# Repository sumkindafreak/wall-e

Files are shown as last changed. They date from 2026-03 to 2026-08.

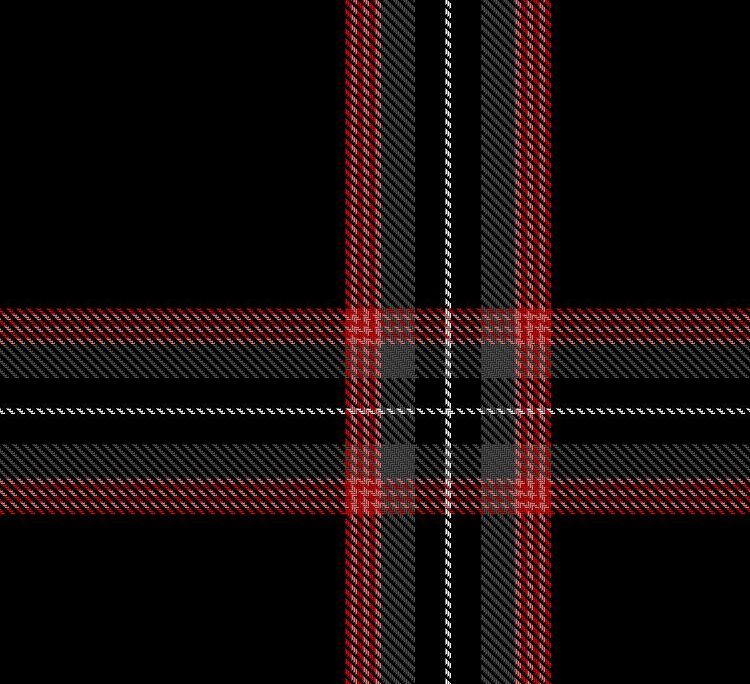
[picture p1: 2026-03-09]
wall-e electronic mounts/tartanimageprototype.jpeg

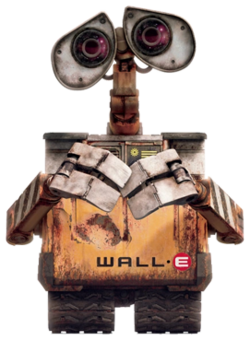
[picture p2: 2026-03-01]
webui/assets/walle-character.png

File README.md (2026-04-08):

# WALL-E Multi-Node Robotics Platform




Distributed firmware for a life-size **WALL-E**-style robot: multiple **ESP32** nodes, a **browser operator UI (LROS)**, shared libraries, and coordination over **Wi-Fi**, **ESP-NOW**, **OTA**, and a **node health** heartbeat.

**Repository:** [github.com/sumkindafreak/wall-e](https://github.com/sumkindafreak/wall-e)

---

## Table of contents

1. [Goals](#high-level-goals)
2. [Architecture](#architecture)
3. [Nodes at a glance](#nodes-at-a-glance)
4. [Communication](#communication-stack)
5. [Hardware overview](#hardware-overview)
6. [Setup](#setup)
7. [Development workflow](#development-workflow)
8. [Media](#media-placeholders)
9. [Roadmap](#roadmap)
10. [Documentation index](#documentation-index)

---

## High-level goals

| Goal | How the repo supports it |
|---|---|
| **Separation of concerns** | No single MCU runs UI, motors, audio, vision, and charging logic together. |
| **Low-latency control** | Master ↔ base uses **ESP-NOW** with packed structs; same RF channel as the base AP. |
| **Observability** | **Node health** (`WNHT`) and dock **beacon** packets expose state to the base and UI. |
| **Safe docking** | Dock station manages charge current, presence sensing, and **IR alignment** hints. |
| **Operator flexibility** | Physical **CYD master**, optional **LROS** in a browser, both ultimately commanding the **base**. |

---

## Architecture

### Diagram (Mermaid)

> Renders on GitHub; for plain text see the ASCII block below.

```mermaid
flowchart TB
  subgraph operator["Operator layer"]
    MC[wall_e_master_controller\nCYD touchscreen]
    WEB[webui / LROS\nbrowser]
  end

  subgraph brain["Base brain"]
    BASE[main_wall_E_base\nESP32-S3]
  end

  subgraph satellites["Satellite nodes"]
    AUD[audio_esp]
    VIS[vision_node / vision_node_arduino]
  end

  subgraph home["Home / charge"]
    DOCK[dock_station]
  end

  MC -->|"ESP-NOW ControlPacket / TelemetryPacket"| BASE
  WEB -->|"HTTP API"| BASE
  AUD <-->|"ESP-NOW"| BASE
  VIS -->|"ESP-NOW VisionPacket"| BASE
  BASE <-->|"ESP-NOW beacon + commands"| DOCK
  MC -.->|"same Wi-Fi channel"| BASE
  AUD -.->|"same channel"| BASE
  VIS -.->|"same channel"| BASE
  DOCK -.->|"optional home Wi-Fi"| DOCK
```

### Diagram (ASCII)

```
  ┌─────────────────────┐         ┌─────────────────────┐
  │ Master controller   │         │ Web UI (LROS)       │
  │ (ESP32 + touch)     │         │ Browser → HTTP      │
  └──────────┬──────────┘         └──────────┬──────────┘
             │ ESP-NOW                      │ HTTP
             │ Control / Telemetry           │
             ▼                               ▼
  ┌──────────────────────────────────────────────────────┐
  │ main_wall_E_base — Base brain (ESP32-S3)              │
  │ Motors · servos · AP · web server · ESP-NOW hub       │
  └─┬──────────────┬──────────────┬──────────────────────┘
    │              │              │
    │ ESP-NOW      │ ESP-NOW      │ ESP-NOW
    ▼              ▼              ▼
┌────────┐   ┌──────────┐   ┌─────────────┐
│ audio  │   │ vision   │   │ dock_station │
│ _esp   │   │ _node     │   │ charge + IR  │
└────────┘   └──────────┘   └─────────────┘
```

---

## Nodes at a glance

| Node | Folder | Responsibility |
|---|---|---|
| **Master controller** | `wall_e_master_controller/` | Touch UI, `ControlPacket` TX, `TelemetryPacket` RX; optional **SD card** (SPI) for macros, logs, profiles — see [wall_e_master_controller/README.md](wall_e_master_controller/README.md). |
| **Base (locomotion)** | `main_wall_E_base/` | Motors, servos, Wi-Fi AP, HTTP (LROS, motion policy, sequences, optional EVE UART bridge), ESP-NOW RX/TX, docking FSM, node health registry. |
| **Audio** | `audio_esp/` | Audio / DFPlayer path; ESP-NOW side channel to base. |
| **Vision** | `vision_node/` or `vision_node_arduino/` | Camera + motion; `VisionPacket_t` to base. |
| **Dock** | `dock_station/` | Charging, sensors, IR alignment receivers, dock beacon + `ir_align_hint`. |
| **Web UI** | `webui/` | Static LROS assets; talks to **base** over HTTP (not ESP-NOW). |

Per-folder details: [wall_e_master_controller/README.md](wall_e_master_controller/README.md) · [main_wall_E_base/README.md](main_wall_E_base/README.md) · [audio_esp/README.md](audio_esp/README.md) · [vision_node/README.md](vision_node/README.md) · [dock_station/README.md](dock_station/README.md) · [webui/README.md](webui/README.md) · [lib/README.md](lib/README.md)

---

## Communication stack

| Layer | Mechanism | Typical use |
|---|---|---|
| **Operator → base (real-time)** | ESP-NOW | `ControlPacket` / `TelemetryPacket` ([protocol.h](wall_e_master_controller/protocol.h)). |
| **Browser → base** | HTTP on LAN or AP | LROS fetches JSON or forms; see `web_server.cpp` on base. |
| **Vision / audio ↔ base** | ESP-NOW | Magic + length dispatch in base receiver. |
| **Base ↔ dock** | ESP-NOW | `DockBeaconPacket_t` (~10 Hz when Wi-Fi enabled on dock), dock commands. |
| **Heartbeat** | ESP-NOW | `WalleNodeHealthPacket_t` — magic `WNHT`, versioned struct ([node_health_protocol.h](main_wall_E_base/main/node_health_protocol.h)). |
| **Provisioning / OTA** | Wi-Fi STA/AP | Base AP `WALL-E-Control`; OTA [OTA_README.md](OTA_README.md). |

**Critical:** ESP-NOW peers must use the **same Wi-Fi channel** as the base access point (see [ARCHITECTURE.md](ARCHITECTURE.md)).

---

## Hardware overview

| Role | MCU (typical) | Notes |
|---|---|---|
| Master | ESP32 (e.g. CYD 2432S028) | TFT + touch; no motors. |
| Base | ESP32-S3 | Tank drive, servos (I2C PWM), VL53L1X, obstacle bumpers; no modulated **IR TX** toward the dock in firmware. |
| Audio | ESP32-S3 | DFPlayer or project-specific audio chain. |
| Vision | ESP32-S3 + PSRAM | OV2640; pin map is board-specific. |
| Dock | ESP32-S3 | Charge MOSFET, ACS712, VL6180 I2C, TSOP IR receivers, NeoPixel, TFT. |

**Dock alignment:** WALL-E emits **modulated IR** from two LEDs; the dock’s two receivers drive **`ir_align_hint`** on the beacon; the base **ALIGN** state uses that over ESP-NOW.

**Pins:** Authoritative maps live in each project’s `*_config.h`. README tables are summaries only.

---

## Setup

### Prerequisites

- [PlatformIO](https://platformio.org/) (recommended) **or** Arduino IDE 2.x + ESP32 board support.
- USB cable per module; serial **115200** baud unless a README says otherwise.

### Clone and build

```bash
git clone https://github.com/sumkindafreak/wall-e.git
cd wall-e
```

Examples:

```bash
cd main_wall_E_base && pio run -e wall_e_brain_s3
cd ../wall_e_master_controller && pio run -e cyd_esp32_2432s028
cd ../dock_station && pio run -e dock_esp32
```

Shared Arduino libraries: [`lib/`](lib/README.md) — referenced via `lib_extra_dirs` in PlatformIO.

### OTA

See **[OTA_README.md](OTA_README.md)** — web update URL for the base, `espota`, and `ota_build_all` scripts.

### RF / MAC / channel

- After flashing, each ESP32 has a factory **Wi-Fi MAC**; any stored peer list may need refresh.
- Align **Wi-Fi channel** with the base AP for ESP-NOW (document your router/AP channel if nodes use STA).
- **Dock ID:** `DOCK_ID` in `dock_config.h` — set uniquely if multiple docks exist.

---

## Development workflow

1. **Pick a node** — Build only what you change (`pio run -e <env>`).
2. **Keep protocols in sync** — `dock_protocol.h` and `node_health_protocol.h` are duplicated in several trees until consolidated; change all copies or document follow-up.
3. **Test on hardware** — Note board variant (DevKit, CYD, etc.) in PRs.
4. **Document** — Update the module `README.md` when pins, env names, or protocols change.

More detail: [CONTRIBUTING.md](CONTRIBUTING.md).

---

## Media placeholders

| Slot | Suggested path |
|---|---|
| Hero build photo | `docs/media/hero.jpg` |
| Master UI | `docs/media/controller.jpg` |
| Dock + robot | `docs/media/dock.jpg` |
| Demo GIF | `docs/media/demo.gif` |

Create `docs/media/` when you add assets, or host externally and link here.

---

## Roadmap

| Item | Notes |
|---|---|
| Single **`protocols/`** include tree | Remove duplicate headers; CI compile check. |
| Vision channel sync guide | One doc for “set router channel = base channel”. |
| LROS ↔ base WebSocket (optional) | Lower latency than polling for some panels. |
| CI matrix | Build `main_wall_E_base`, `dock_station`, `wall_e_master_controller` on push. |
| SPDX license file | Clarify redistribution terms. |

---

## Documentation index

| Document | Content |
|---|---|
| [ARCHITECTURE.md](ARCHITECTURE.md) | Design philosophy, protocols, docking, OTA, WebUI chain, motion authority (LROS vs CYD). |
| [CONTRIBUTING.md](CONTRIBUTING.md) | Branches, commits, conventions, new nodes, LROS. |
| [FOLDER_STRUCTURE.md](FOLDER_STRUCTURE.md) | Optional repo reorganization (no code moves yet). |
| [REPO_AUDIT.md](REPO_AUDIT.md) | Gaps, naming, refactors to consider. |
| [OTA_README.md](OTA_README.md) | Over-the-air updates. |

---

## License

Add a `LICENSE` file to the repository root when you choose a license (MIT, Apache-2.0, etc.). Until then, treat usage as **all rights reserved** unless you state otherwise.

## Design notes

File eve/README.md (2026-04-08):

# EVE companion firmware (ESP32-S3)

UART-framed link to WALL-E (hand pogo), state machine, and hooks for eyes / ToF / servos / NeoPixel / DFPlayer.

## Requirements

- [PlatformIO](https://platformio.org/) (or Arduino IDE with manual lib install — PIO recommended).
- Board: **ESP32-S3** with **16 MB flash / 8 MB PSRAM** (N16R8 class), same family as WALL-E.

## Arduino IDE (alternative)

Open the sketch folder **`arduino_ide/EVE_Companion/`** and follow **`arduino_ide/README.md`**.

## Build (PlatformIO)

```bash
cd eve
pio run
```

## Upload

```bash
pio run -t upload
pio device monitor
```

## Configuration

Edit `include/config.h`:

- `EVE_UART_TX_PIN` / `EVE_UART_RX_PIN` — hand link (default 17/18; **must match your PCB**).
- Feature flags: `EVE_ENABLE_NEOPIXEL`, `EVE_ENABLE_SERVOS`, etc. (keep off until wired).
- DFPlayer UART pins must **not** overlap the hand UART.

## WALL-E side

Peer UART on the base must use the **crossover** convention: WALL-E TX → EVE RX, WALL-E RX ← EVE TX, **GND** common.

The base (`main_wall_E_base`) can optionally run **`eve_uart_bridge`** on **UART2** (default **TX GPIO 18**, **RX GPIO 17** — see `main/eve_uart_bridge.h`) and expose link status as **`GET /api/eve/status`** for LROS. Pins must match your harness; keep **EVE** and **base** `config` in agreement.

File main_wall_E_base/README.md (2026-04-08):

# Base Locomotion Node (“Brain”)

The **ESP32-S3** central node: **tank drive**, **servos**, **local TFT**, **Wi-Fi softAP** (`WALL-E-Control`), **HTTP** web server (including LROS integration points), **ESP-NOW** hub for master, vision, audio, and dock traffic, plus **autonomous docking** and **node health** aggregation.

---

## Purpose

- Execute **motor** commands from the master (ESP-NOW) with **fail-safe** stop when commands time out.
- Host **REST/HTML** endpoints used by the web UI and OTA page.
- **Fuse** dock beacon RSSI, optional **`ir_align_hint`** from the dock, **VL53L1X** approach, and bumper inputs for docking behavior.
- **Aggregate** telemetry for the master and optional UI.

---

## Hardware (typical)

| Subsystem | Notes |
|---|---|
| **MCU** | ESP32-S3 DevKit-class (e.g. N16R8) |
| **Motors** | L298N or compatible H-bridge |
| **Servos** | PCA9685 over I2C (`servo_manager`) |
| **Sensing** | VL53L1X ToF, rear dock IR beam, **front IR TX** on GPIO **21** / **38** (modulated — see `ir_beacon_receivers`), IMU; optional sonar/GPS when enabled in code |
| **Display** | ST7735/ST7789 (`display_manager`) |

**Authoritative pins:** `main/dock_sensors.h` and other `main/*.h` — **not** this README alone.

---

## Dependencies

- PlatformIO environment **`wall_e_brain_s3`** — [platformio.ini](platformio.ini).
- **`lib_extra_dirs = ../lib`** for `walle_emotion_pose` and event stubs.
- **Pololu VL53L1X**, **Adafruit PWM Servo**, **Adafruit GFX**, **MPU6050**, **TinyGPSPlus**, etc. (see `lib_deps`).

---

## Build and flash

```bash
cd main_wall_E_base
pio run -e wall_e_brain_s3
pio run -e wall_e_brain_s3 -t upload
```

**Arduino IDE:** [ARDUINO_IDE_QUICK_START.md](ARDUINO_IDE_QUICK_START.md) — root `main.ino` includes `main/main.ino`.

---

## Node ID and addressing

| Item | Value |
|---|---|
| **Node health ID** | `WALLE_NODE_BASE` = **0** — [main/node_health_protocol.h](main/node_health_protocol.h) |
| **ESP-NOW** | Base acts as **RX hub**; peers must be on the **same channel** as this module’s AP |

---

## Communication responsibilities

| Peer | Protocol |
|---|---|
| **Master** | `ControlPacket` in, `TelemetryPacket` out |
| **Vision** | `VisionPacket_t` (magic `VISION_MAGIC`) |
| **Dock** | `DockBeaconPacket_t`, dock commands — [main/dock_protocol.h](main/dock_protocol.h) |
| **Audio** | Audio-specific (see `audio_espnow` / protocols) |
| **Browser** | HTTP — see `web_server.cpp` |
| **EVE (optional UART)** | Framed UART (same framing as `eve/`) — [main/eve_uart_bridge.cpp](main/eve_uart_bridge.cpp); status **`GET /api/eve/status`** |

### HTTP / LROS (selected endpoints)

Implemented in **`main/web_server.cpp`** (and related modules). Highlights:

| Area | Notes |
|---|---|
| **Motion policy** | `motion_authority` — **`any`** / **`cyd_only`** / **`web_only`** (CYD ESP-NOW vs LROS HTTP). **`GET /api/motion/authority`**, **`GET /api/motion/authority/set?mode=...`** (token if configured). **`GET /api/motion/operator`** reports policy + `motion_policy_allows_cyd` / `motion_policy_allows_web`. |
| **Sequences** | `sequence_engine` / `sequence_api` — LROS timelines; steps may include optional **`when`** (battery, dock FSM, vision event). |
| **Navigation** | `/api/navigation/*` — POST route may require API token if set. |
| **Vision** | **`GET /api/vision/events`** — recent vision lifecycle events (ring buffer). |
| **Security / ops** | Optional **`X-Wall-E-Token`** (or `?token=`) when a token is stored in NVS; **`POST /api/security/token`** (JSON body). **`GET /api/audit`**, **`GET /api/dashboard`** (aggregated status). |

ESP-NOW **E-stop** from the master is not suppressed by motion policy; HTTP drive is gated when policy denies web.

---

## Docking

- **Autonomous docking FSM:** [main/AUTONOMOUS_DOCKING.md](main/AUTONOMOUS_DOCKING.md).
- **IR:** Two transmitters on WALL-E (`dock_ir_transmitters.h`, default GPIO **21** / **38**); two receivers on the dock feed **`ir_align_hint`** on the ESP-NOW beacon for **ALIGN**.

---

## Calibration

- **Battery ADC** — `battery_monitor` scale/offset.
- **Motors** — Trim in `motor_control` if implemented.
- **VL53L1X** — I2C address, mounting, and field of view.
- **Dock thresholds** — `dock_sensors.h`, `autonomous_docking.h`.

---

## OTA

- **Web:** `http://192.168.4.1/update` when the AP is up — [../OTA_README.md](../OTA_README.md).

---

## Known quirks and limitations

- **`build_src_filter`** may exclude some `walle_emotion_pose` sources to avoid duplicate symbols — check `platformio.ini` before adding second copies.
- **Autonomy** — Some engine init may be commented in `main.ino` during bring-up; verify before expecting full auto behavior.
- **HTTP API** — Intended for **trusted LAN**; optional **`POST /api/security/token`** sets a shared token for mutating routes (see table above). Do not expose unauthenticated control to the public internet.

---

## See also

- [../ARCHITECTURE.md](../ARCHITECTURE.md)  
- [../README.md](../README.md)

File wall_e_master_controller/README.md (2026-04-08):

# Master Controller (CYD Touch Desk)

The **handheld operator station** for WALL-E: resistive touch UI, drive abstraction, and **ESP-NOW** exchange of **`ControlPacket`** (out) and **`TelemetryPacket`** (in) with the base.

---

## Purpose

- Send normalized **left/right** speed, **precision** mode, **behaviour/mood**, **actions** (scan, beep, dock go/cancel), and **system flags** (E-stop, etc.).
- Optional **servo target** array for head/arms when the protocol and base build support it.
- Display **battery**, autonomy, and safety-related telemetry from the base.

---

## Hardware

| Item | Detail |
|---|---|
| **Typical board** | ESP32 **CYD** 2432S028 — 243×320 TFT + resistive touch |
| **PlatformIO env** | `cyd_esp32_2432s028` ([platformio.ini](platformio.ini)) |
| **Optional peripherals** | SX1509 IO expander, ADS1015 ADC, GPS (see `lib_deps`) |
| **SD card (SPI)** | **CS** GPIO **5**, **MOSI** 23, **MISO** 19, **SCK** 18 — see [sd_manager.h](sd_manager.h). Initialized in [wall_e_master_controller.ino](wall_e_master_controller.ino) after TFT init; **FAT32** recommended. |

---

## SD card (persistent storage)

The firmware mounts an SD card when present and uses it as the backing store for **macros**, **animations**, **profile import/export**, **story memory**, and **buffered logs** under **`/wall_e/`** (see `sd_manager.cpp`).

| Topic | Detail |
|---|---|
| **Boot** | `sdInit()` runs after `tft.init()` (up to **3** mount retries). If mount fails, the controller continues **without** SD; `sdIsAvailable()` is false. |
| **Logging** | `sdLog()` / `sdLogFlush()`; `sdUpdate()` is called from the main loop for periodic log flush. |
| **Macros** | `macroInit()` runs after SD init; record/save/load uses SD when available. |
| **System status** | `system_status` debug strings can include **`SD_OK`** / **`SD_--`** when `systemStatusFormatDebug()` is used. |

The **dev console** (`dev_console.*`) can draw SD status when integrated into the UI; it is optional and not required for SD to work.

---

## Dependencies

- **PlatformIO** + `espressif32` / Arduino framework.
- Libraries: **TFT_eSPI**, **XPT2046_Touchscreen**, **SparkFun SX1509**, **Adafruit ADS1X15**, **TinyGPSPlus** (exact versions in `platformio.ini`).
- **`lib_extra_dirs = ../lib`** for shared emotion-pose stubs.

---

## Build and flash

```bash
cd wall_e_master_controller
pio run -e cyd_esp32_2432s028
pio run -e cyd_esp32_2432s028 -t upload
```

---

## Node ID and addressing

| Item | Value |
|---|---|
| **Node health ID** | `WALLE_NODE_MASTER` = **1** — [node_health_protocol.h](node_health_protocol.h) (keep in sync with other copies in the repo) |
| **MAC address** | Factory Wi-Fi MAC per chip; no fixed MAC in source |
| **ESP-NOW channel** | Must match the **Wi-Fi channel** used by the **base access point** (`WALL-E-Control`) |

---

## Communication responsibilities

| Direction | Content |
|---|---|
| **→ Base** | Packed `ControlPacket` — [protocol.h](protocol.h) |
| **← Base** | Packed `TelemetryPacket` |
| **Transport** | ESP-NOW (not HTTP) |

The master does **not** talk to the dock or vision nodes directly in the stock design.

---

## OTA

- **ArduinoOTA** on port **3232** when joined to the WALL-E AP — see [../OTA_README.md](../OTA_README.md).

---

## Calibration and setup

- **Touch** — Calibrate in `touch_input` / profile code for your CYD revision.
- **Display** — UI layout in `profiles` / `ui_draw` for 2432S028 resolution.

---

## Known quirks and limitations

- **Dual control:** If LROS (browser) also commands the base while the master is driving, define an operator policy to avoid conflicting commands.
- **ESP-NOW range** — Same as Wi-Fi PHY; obstacles and antenna orientation matter.
- **Telemetry** — Field availability depends on base firmware build (autonomy features may be disabled).

---

## See also

- [../ARCHITECTURE.md](../ARCHITECTURE.md)  
- [../README.md](../README.md)

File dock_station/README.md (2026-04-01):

# Dock Station (Smart Charging Crate)

**ESP32-S3** fixed install: **charge control** (MOSFET + **ACS712**), **dock presence** (GPIO motion sensor, VL6180 ToF, optional sonar, obstacles), **IR alignment receivers**, **arrow indicators**, **NeoPixel + TFT**, **ESP-NOW beacon** for homing, optional **home Wi-Fi**, and **OTA**.

---

## Purpose

- Run a **charging state machine** (not docked → idle → charging → charged / fault) with **current-based** thresholds.
- Broadcast **`DockBeaconPacket_t`** at **10 Hz** when ESP-NOW is active (`ESPNOW_BEACON_INTERVAL_MS` = 100 ms in [dock_config.h](dock_config.h)) — includes **`ir_align_hint`** when IR guidance runs.
- Provide **visual alignment** via arrow MOSFETs driven from **`dock_alignment`** / **`dock_ir_guidance`**.
- Optional **call WALL-E** switch and light sequences.

---

## Hardware summary

| Area | Config keys (see [dock_config.h](dock_config.h)) |
|---|---|
| Charge enable | `PIN_MOSFET_GATE` |
| Current sense | `PIN_ACS712_ADC` |
| VL6180 ToF | `PIN_VL6180_SDA`, `PIN_VL6180_SCL` |
| Alignment IR | `PIN_ALIGN_LEFT`, `PIN_ALIGN_RIGHT` (TSOP: **LOW** = IR seen) |
| Motion (presence) | `PIN_MOTION_SENSOR` / `PIN_IR_BEAM` (alias; separate from side alignment) |
| Arrows / UI | Arrow MOSFETs, NeoPixel data, TFT SPI, call switch |

**Important:** Pin tables in old wikis may be wrong. The **comment block at the top of `dock_config.h`** is the authoritative map for this firmware.

---

## Dependencies

- PlatformIO env **`dock_esp32`** — [platformio.ini](platformio.ini).
- **FastLED**, **Adafruit GFX**, **ST7735**, **VL6180X**, **BusIO**.

---

## Build and flash

```bash
cd dock_station
pio run -e dock_esp32
pio run -e dock_esp32 -t upload
```

**Arduino IDE:** Open `dock_station.ino`; sibling `.cpp`/`.h` files compile with the sketch.

---

## Node ID and addressing

| Item | Value |
|---|---|
| **Dock ID** | `DOCK_ID` in `dock_config.h` (default `0x00000001`) — unique per physical dock if multiple exist |
| **Node health ID** | `WALLE_NODE_DOCK` = **3** — [node_health_protocol.h](node_health_protocol.h) |

---

## Communication responsibilities

| Peer | Protocol |
|---|---|
| **Base** | ESP-NOW: beacon, `DOCK_CMD_*`, approach stage — [dock_protocol.h](dock_protocol.h) |
| **Master** | **Indirect** — only via base in stock firmware |

**Wi-Fi:** When `ENABLE_WIFI` is **0**, ESP-NOW beacon traffic may be disabled — base will not receive **`ir_align_hint`** over the air; align using dock **arrows** and local testing only.

---

## Configuration files

- **[dock_config.h](dock_config.h)** — Wi-Fi, thresholds, `USE_VL6180_TOF`, `DOCK_IR_LOST_TIMEOUT_MS`, NeoPixel map, `ENABLE_WIFI`.
- **[dock_protocol.h](dock_protocol.h)** — Must stay **byte-compatible** with [main_wall_E_base/main/dock_protocol.h](../main_wall_E_base/main/dock_protocol.h).

---

## Calibration

- **ACS712:** `ACS712_MV_PER_AMP`, `CURRENT_CALIB_*` in `dock_config.h`.
- **VL6180:** `VL6180_DOCK_MIN_MM` / `VL6180_DOCK_MAX_MM` for “robot in slot” band.
- **IR alignment:** WALL-E base drives two ~38 kHz IR LEDs; dock TSOP inputs — tune debounce in `dock_ir_guidance.cpp` if needed.

---

## OTA

- **ArduinoOTA** hostname **`wall-e-dock`** when on Wi-Fi — [../OTA_README.md](../OTA_README.md).

---

## Known quirks and limitations

- **`ENABLE_WIFI 0`** — Common for bring-up; no OTA/ESP-NOW beacon to base until Wi-Fi stack is enabled and configured.
- **Alignment vs beam** — Side **alignment IR** and **break-beam** are **different** sensors and software paths.
- **TFT/SPI** — Shares bandwidth with sensor polling; see serial for init failures.

---

## Extra documentation

- [TOF050C_VL6180.md](TOF050C_VL6180.md) — VL6180 tuning.

---

## See also

- [../ARCHITECTURE.md](../ARCHITECTURE.md)  
- [../README.md](../README.md)

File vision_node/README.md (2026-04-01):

# Vision Node (PlatformIO — ESP32-S3 + Camera)

**ESP32-S3** with **OV2640** (or compatible) camera: **motion detection**, **clustering**, **centroid**, optional **object class**, **lightweight recognition** (RGB565 colour heuristics, blob, distance band, classification, events), and **ESP-NOW** transmission of **`VisionPacket_t`** to the base.

Recognition runs on a **~150 ms** cadence: one **RGB565** QQVGA frame is captured, analysed, then the sensor returns to **grayscale** for motion (pins unchanged). No ML / OpenCV.

---

## Purpose

- Offload vision from the base; provide **target X/Y**, **bounding box**, **motion flag**, and **frame ID** for head/eye tracking or behaviour.

---

## Hardware

| Item | Detail |
|---|---|
| **MCU** | ESP32-S3 with **PSRAM** strongly recommended |
| **Sensor** | OV2640 — **pin config is board-specific**; edit `src/main.cpp` camera structure |

---

## Dependencies

- PlatformIO — [platformio.ini](platformio.ini).
- ESP32 camera driver (Arduino-ESP32).
- **Same Wi-Fi channel** as the base AP for ESP-NOW (critical).

---

## Build and flash

```bash
cd vision_node
pio run
pio run -t upload
```

---

## Node ID and addressing

| Item | Value |
|---|---|
| **Logical ID** | `WALLE_NODE_VISION` = **4** in node health documentation |
| **Health packets** | If implemented, must match `WalleNodeHealthPacket_t` layout |

---

## Communication responsibilities

| Peer | Protocol |
|---|---|
| **→ Base** | `VisionPacket_t` — magic `VISION_MAGIC` — [include/vision_protocol.h](include/vision_protocol.h) |
| **Master** | **None** — vision does not target the CYD directly |

---

## Calibration

- **Motion:** `motion_detect.h` — `motionThreshold`, `minMotionPixels`, `smoothFactor`, `occlusionTimeoutMs`.
- **Camera:** Exposure, resolution, grayscale pipeline in `main.cpp` for your lighting.

---

## Canonical vs Arduino duplicate

This folder is the **PlatformIO** reference. A parallel **Arduino IDE** tree exists at **`../vision_node_arduino/`**. Pick **one** per deployment to avoid protocol drift; see root [README.md](../README.md).

---

## Known quirks and limitations

- **Frame rate** — Motion pipeline and ESP-NOW rate should be tuned to avoid CPU starvation.
- **Wi-Fi channel** — If ESP-NOW “goes silent,” verify router/AP channel matches the base.

---

## See also

- [../ARCHITECTURE.md](../ARCHITECTURE.md)  
- [../main_wall_E_base/main/vision_behaviour.cpp](../main_wall_E_base/main/vision_behaviour.cpp)

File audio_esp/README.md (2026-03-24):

# Audio Node (`audio_esp`)

Dedicated **ESP32-S3** firmware for WALL-E **sound**: playback, voice, and **ESP-NOW** coordination with the base. Uses **DFRobot DFPlayer Mini** ([platformio.ini](platformio.ini)) and shared headers from **`../wall_e_audio`** when that path exists in your workspace.

---

## Purpose

- Offload audio from the base so motor control and audio decoding are not competing on the same critical path.
- Send/receive **audio-related** ESP-NOW traffic (see `audio_protocol.h`, `espnow_manager`).

---

## Hardware

| Item | Detail |
|---|---|
| **Board** | `esp32-s3-devkitc-1` (see `platformio.ini` env `esp32-s3-devkitc-1`) |
| **Audio** | DFPlayer Mini + microSD, UART wiring per `audio_esp.ino` |

---

## Dependencies

- PlatformIO, `espressif32`, Arduino.
- **DFRobotDFPlayerMini** library.
- **Build flags:** `-I ../wall_e_audio` for shared protocol headers.

---

## Build and flash

```bash
cd audio_esp
pio run -e esp32-s3-devkitc-1
pio run -e esp32-s3-devkitc-1 -t upload
```

---

## Node ID and addressing

| Item | Value |
|---|---|
| **Node health ID** | `WALLE_NODE_AUDIO` = **2** — [node_health_protocol.h](node_health_protocol.h) (keep in sync) |
| **Channel** | ESP-NOW requires the **same Wi-Fi channel** as the base AP |

---

## Communication responsibilities

| Path | Role |
|---|---|
| **↔ Base** | ESP-NOW; master does **not** speak to audio directly in the stock architecture |
| **Master** | Indirect — via base telemetry or future bridging |

---

## Calibration

- **DFPlayer:** UART baud (typically 9600), busy pin, volume curve.
- **SD card:** File naming (`0001.mp3` style) and folder layout per DFPlayer documentation.

---

## Known quirks and limitations

- **`wall_e_audio` path** — If the sibling folder is missing, add it or adjust `build_flags` includes.
- **Latency** — DFPlayer is not sample-accurate; gapless playback has limits.

---

## See also

- [../ARCHITECTURE.md](../ARCHITECTURE.md)  
- [../lib/walle_audio_events/walle_audio_events.h](../lib/walle_audio_events/walle_audio_events.h)

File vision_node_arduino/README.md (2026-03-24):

# Vision Node (Arduino IDE)

Arduino-IDE–friendly layout for the **vision** pipeline: ESP32-S3 + camera, **motion detection**, and **ESP-NOW** broadcast of **`VisionPacket_t`** to the base — same logical role as [vision_node](../vision_node/README.md) (PlatformIO).

---

## Purpose

- Same as PlatformIO vision node for users who prefer a single `.ino` entry point without PlatformIO.

---

## Hardware

- ESP32-S3 + OV2640 (board-specific pins in sources).

---

## Dependencies

- ESP32 Arduino core, camera driver.
- **`vision_protocol.h`** must match [vision_node](../vision_node/include/vision_protocol.h) and base expectations.

---

## Flashing (Arduino IDE)

1. Open the sketch folder containing `vision_node_arduino.ino`.
2. Select the correct **ESP32-S3** board and **USB** port.
3. Compile and upload.

---

## Node ID and addressing

| Item | Detail |
|---|---|
| **Logical role** | Vision satellite — `WALLE_NODE_VISION` in docs |
| **MAC** | Per-device after flash |

---

## Communication responsibilities

- **ESP-NOW** — `VisionPacket_t` to base; **same RF channel** as base AP.

---

## Calibration

- See [vision_node/README.md](../vision_node/README.md) motion parameters.

---

## Maintenance policy

If both `vision_node/` and `vision_node_arduino/` are kept:

- **Document which is canonical** in the root README.
- **Change `vision_protocol.h` in one place** and copy to the other, or symlink, to avoid struct mismatch.

---

## See also

- [../vision_node/README.md](../vision_node/README.md)  
- [../ARCHITECTURE.md](../ARCHITECTURE.md)

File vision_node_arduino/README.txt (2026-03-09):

WALL-E Vision Node - Arduino IDE
================================

Board: ESP32S3 Dev Module

Settings:
- Flash Size: 16MB (128Mb)
- PSRAM: OPI PSRAM
- Partition Scheme: Default 4MB with spiffs

Libraries: None required (esp_camera, WiFi, esp_now, SD_MMC come with ESP32 core)

SD card (rear slot):
- 1-bit SDMMC: CLK=39, CMD=40, D0=38 (default for ESP32-S3-CAM N16R8).
  If your board differs, edit SD_PIN_CLK, SD_PIN_CMD, SD_PIN_D0 in the .ino.
- When a card is present, motion events are appended to /motion_log.csv
  (millis, frameId, motion, targetX, targetY, objectClass, objectSize).
- Set SD_LOG_ENABLE to 0 to disable SD logging.

WiFi + Camera snapshot (for web UI):
- Vision node connects to base brain AP (WALL-E-Control / walle1234).
- Serves GET /snapshot (JPEG). Base brain web UI embeds the image.
- If WiFi fails, ESP-NOW motion data still works; snapshot disabled.

Onboard RGB LED (standard 3-pin):
- Uses PWM (LEDC) on GPIO 21=R, 47=G, 48=B by default. If your board uses different
  pins, edit LED_PIN_R, LED_PIN_G, LED_PIN_B in the .ino. Set LED_ENABLE to 0
  to disable. Status: red=init, blue=idle, green=motion detected.

Upload: File → Open → select vision_node_arduino.ino
       Tools → Board → ESP32S3 Dev Module
       Tools → Port → (your COM port)
       Sketch → Upload

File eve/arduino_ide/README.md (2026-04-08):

# EVE companion — Arduino IDE

## Folder layout

Arduino IDE 2.x expects **one sketch folder** whose name matches the `.ino` file:

```
arduino_ide/
  README.md          (this file)
  EVE_Companion/
    EVE_Companion.ino
    config.h
    eve_protocol.h
    uart_link.h
    uart_link.cpp
    state_machine.h
    state_machine.cpp
    ... (other .h / .cpp tabs)
```

**Open** `EVE_Companion/EVE_Companion.ino` in Arduino IDE (File → Open). All `.cpp` / `.h` files in the same folder appear as tabs and compile together.

## Board setup

1. Install **esp32** by Espressif Systems:  
   *File → Preferences → Additional boards manager URLs* (if needed), then *Tools → Board → Boards Manager* → search **esp32** → install current stable (2.x or 3.x).

2. Select board: **ESP32S3 Dev Module** (or your exact module).

3. For **N16R8** (16 MB flash, 8 MB OPI PSRAM), set:
   - **Flash size:** 16 MB (if listed)
   - **PSRAM:** OPI PSRAM / Enabled (wording varies by core version)
   - **USB CDC On Boot:** Enabled (often needed for USB serial on S3)

4. **Port:** pick the COM port for your USB cable.

## Library

Install **ArduinoJson** version **6.x**:

- *Sketch → Include Library → Manage Libraries…* → search **ArduinoJson** → install **ArduinoJson** by **Benoit Blanchon** (v6.21.x or newer).

## Compile & upload

1. Open `EVE_Companion.ino`.
2. Click **Verify** then **Upload**.
3. Open **Serial Monitor** at **115200** baud.

You should see `[EVE][UART]` and periodic `EVE_HELLO` until WALL-E answers with a framed `WALL_E_ACK`.

## Keeping in sync with PlatformIO

The files under `EVE_Companion/` are meant to stay **logically identical** to `eve/src/` + `eve/include/` from the repo root. After editing one tree, copy changes to the other if you use both tools.

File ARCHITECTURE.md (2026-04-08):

# WALL-E — System Architecture

This document describes how controllers interact, how **node health** works, how **docking** and **emotion pose** fit in, how **OTA** is used, and how **LROS**, the **master**, and **nodes** connect. For an optional repository layout proposal see [FOLDER_STRUCTURE.md](FOLDER_STRUCTURE.md).

---

## Table of contents

1. [Multi-controller philosophy](#1-multi-controller-philosophy)
2. [WebUI → Base → Nodes chain](#2-webui--base--nodes-communication-chain)
3. [Node health protocol](#3-node-health-protocol)
4. [Emotion pose library](#4-emotion-pose-library)
5. [Docking guidance](#5-docking-guidance-logic)
6. [Control and telemetry (master ↔ base)](#6-control-and-telemetry-master--base)
7. [Vision and dock protocols](#7-vision-and-dock-protocols)
8. [OTA update flow](#8-ota-update-flow)
9. [Future consolidation](#9-future-consolidation)

---

## 1. Multi-controller philosophy

### Separation of concerns

| Concern | Owner |
|---|---|
| Operator intent (speed, mode, E-stop, actions) | Master controller (`wall_e_master_controller`) |
| Actuation, safety timers, sensor fusion | Base (`main_wall_E_base`) |
| Charging policy, arrows, dock IR | Dock (`dock_station`) |
| Specialized processing | Audio / vision satellites |

The base **does not** embed the CYD LVGL/touch stack. The master **does not** drive GPIO to motor drivers. Boundaries are **binary protocols** (packed structs) over ESP-NOW or HTTP.

### Why ESP-NOW and Wi-Fi together

| Transport | Role |
|---|---|
| **ESP-NOW** | Low overhead for periodic control and small sensor frames; requires **same Wi-Fi channel** as the interface used for coordination (typically the base’s AP channel). |
| **Wi-Fi** | SoftAP for provisioning (`WALL-E-Control`), HTTP for LROS and web OTA, optional STA to home LAN. |

```mermaid
sequenceDiagram
  participant M as Master (ESP-NOW)
  participant B as Base
  participant W as WebUI (HTTP)
  M->>B: ControlPacket
  B->>M: TelemetryPacket
  W->>B: HTTP (API routes)
  Note over M,B: Same RF channel as base AP for ESP-NOW
```

---

## 2. WebUI → Base → Nodes communication chain

| Path | Direction | Technology |
|---|---|---|
| **LROS → Base** | Browser calls **HTTP** endpoints implemented in `main_wall_E_base/main/web_server.cpp` | REST-style handlers, JSON where implemented |
| **Master → Base** | **ESP-NOW** `ControlPacket` | Not HTTP |
| **Base → Master** | **ESP-NOW** `TelemetryPacket` | — |
| **Base ↔ Dock** | **ESP-NOW** `DockBeaconPacket_t`, `DockCommandPacket_t`, approach stage | Dock often on home Wi-Fi when `ENABLE_WIFI`; beacon includes telemetry fields |
| **Vision → Base** | **ESP-NOW** `VisionPacket_t` | Vision does not talk to the master directly |
| **Audio ↔ Base** | **ESP-NOW** (audio-specific packets / status) | See `audio_esp` and `audio_protocol.h` |

**Operational caution:** If **both** LROS and the master can command motion, conflicting drive commands are possible. The base implements **`motion_authority`** (`any` / `cyd_only` / `web_only`) in `main_wall_E_base/main/motion_authority.cpp` and exposes it via **`GET /api/motion/operator`** and **`/api/motion/authority*`** — see [main_wall_E_base/README.md](main_wall_E_base/README.md).

```mermaid
flowchart LR
  subgraph clients["Clients"]
    LROS[Browser LROS]
    CYD[Master CYD]
  end
  subgraph base["Base"]
    HTTP[HTTP server]
    EN[ESP-NOW stack]
  end
  LROS -->|HTTP| HTTP
  CYD -->|ESP-NOW| EN
  HTTP --> EN
```

---

## 3. Node health protocol

### Message format

- **Magic:** ASCII `WNHT` → `0x574E4854`
- **Version:** `1` (`WALLE_NODE_HEALTH_VERSION`)
- **Struct:** `WalleNodeHealthPacket_t` — packed fields: `node_id`, `role`, `battery_pct`, `temp_c`, `uptime_ms`, `last_error`, `flags`

Canonical definition: [main_wall_E_base/main/node_health_protocol.h](main_wall_E_base/main/node_health_protocol.h) — **identical copies** exist under other folders; treat any drift as a bug.

### Node IDs

| Value | Constant |
|---|---|
| 0 | `WALLE_NODE_BASE` |
| 1 | `WALLE_NODE_MASTER` |
| 2 | `WALLE_NODE_AUDIO` |
| 3 | `WALLE_NODE_DOCK` |
| 4 | `WALLE_NODE_VISION` |

### Timing and transport

- **Not a hard real-time bus.** Nodes emit health when their firmware schedules it (e.g. dock ESP-NOW path shares airtime with **dock beacon** at **10 Hz** (`ESPNOW_BEACON_INTERVAL_MS` = 100 ms in `dock_config.h`) when Wi-Fi is enabled).
- **Consumers** (e.g. base `node_health_registry`) typically record **last_seen_ms** and infer **offline** if no packet arrives for an application-specific timeout (implementations vary — check `node_health_registry.cpp`).

### Failure modes (conceptual)

| Symptom | Likely causes |
|---|---|
| No health from a node | Wrong Wi-Fi channel, node off, ESP-NOW not initialized, or filtered MAC |
| Stale `uptime_ms` | Node reset or packet not updating |
| `WALLE_NODE_HEALTH_UNKNOWN_BAT` | Node has no battery sense (e.g. dock may report unknown for its own “battery” field) |
| Flags stuck | Fault not cleared, or registry not updated |

---

## 4. Emotion pose library

**Location:** [`lib/walle_emotion_pose/`](lib/README.md)

**Intent:** Separate **emotional state** and **pose intent** from concrete servo PWM. The base applies hardware through existing servo drivers; the master may mirror or preview state.

**Structure:** C++ module with `library.json` under `lib/`; optional thin wrappers in base and master (some builds exclude duplicate `.cpp` via `build_src_filter` — see `main_wall_E_base/platformio.ini`).

---

## 5. Docking guidance logic

End-to-end docking is **layered**; do not conflate unrelated sensors.

| Layer | Mechanism |
|---|---|
| **Search / homing** | Dock `DockBeaconPacket_t` at ~10 Hz; base uses RSSI and `dock_id`. |
| **IR alignment** | Base **two IR transmitters** (~38 kHz); dock **two receivers** → **`ir_align_hint`** on the beacon. |
| **Approach stage** | WALL-E sends `DOCK_CMD_APPROACH_STAGE`; dock uses **timeout** to fall back to local IR sensors. |
| **Presence** | VL6180 ToF band, optional **break-beam** (`PIN_IR_BEAM`), obstacle inputs — see `dock_config.h`. |
| **Charge** | ACS712 thresholds + MOSFET gate + state machine (`STATE_*` in dock state module). |

**Documentation rule:** **Alignment IR** (side receivers) and **break-beam** (slot beam) are **different** inputs in firmware.

---

## 6. Control and telemetry (master ↔ base)

Defined in [wall_e_master_controller/protocol.h](wall_e_master_controller/protocol.h).

- **ControlPacket:** `leftSpeed`, `rightSpeed`, `driveMode`, `behaviourMode`, `action`, `systemFlags`, `servoTargets[]`
- **TelemetryPacket:** Battery, current, temperature, mood, autonomy-related fields (see struct for full list)

Both are **packed** for ESP-NOW.

---

## 7. Vision and dock protocols

| Protocol | Magic | Notes |
|---|---|---|
| Vision | `VISION_MAGIC` (`0x5649534E`) | `VisionPacket_t` in `vision_node/include/vision_protocol.h` |
| Dock beacon | `DOCK_BEACON_MAGIC` | `DockBeaconPacket_t` includes `ir_align_hint` — [dock_station/dock_protocol.h](dock_station/dock_protocol.h) |

Keep **byte-compatible** copies under `main_wall_E_base/main/dock_protocol.h` when structs change.

---

## 8. OTA update flow

1. **Build** with PlatformIO → `firmware.bin` under `.pio/build/<env>/`.
2. **Base:** Web upload at `http://192.168.4.1/update` (AP) and/or ArduinoOTA port **3232**.
3. **Controller / dock:** `upload_protocol = espota` with correct IP (see [OTA_README.md](OTA_README.md)).
4. **Batch:** `ota_build_all.ps1` / `ota_build_all.sh`.

mDNS names (`wall-e-base.local`, etc.) depend on LAN multicast support.

---

## 9. Future consolidation

- One **`protocols/`** directory included by all firmware projects
- Optional protocol **version field** on every packet for mixed-firmware fleets
- Documented **channel + MAC** setup script for labs

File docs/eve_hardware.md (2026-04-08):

# EVE companion node — hardware (ESP32-S3 N16R8)

This document matches the **EVE** firmware in `../eve/` and the same MCU class as **WALL-E** (`main_wall_E_base`): **ESP32-S3** module with **16 MB flash** and **8 MB OPI PSRAM** (often sold as **N16R8**).

## Module / board

- **MCU:** ESP32-S3 (Xtensa dual-core, 3.3 V logic).
- **Flash + PSRAM:** N16R8 — use a partition scheme that fits **16 MB flash**; enable **OPI PSRAM** in the build if your module uses it (see `eve/platformio.ini`).
- **Reference pinout:** ESP32-S3-DevKitC-1 style diagrams (e.g. UART1 on **GPIO17 TX / GPIO18 RX**) are a **reference** only. Your **full PCB** is the source of truth — update `eve/include/config.h` to match the routed signals.

## Hand link to WALL-E (primary): UART over pogo pins

**Minimum (4 pins):**

| Pogo | Signal | Notes |
|---|---|---|
| 1 | **GND** | Common ground; star at connector |
| 2 | **WALL-E TX → EVE RX** | One UART data line |
| 3 | **WALL-E RX ← EVE TX** | Other UART data line (full duplex) |
| 4 | *(optional)* **EVE_PRESENT** | Digital: faster “plugged in” before sync (see protocol doc) |

Default firmware UART mapping (DevKit-style, **override in `config.h` if your PCB differs**):

- **Debug / USB serial:** UART0 via USB bridge (typ. **GPIO43/44** — do not use for hand link if reserved for debug).
- **Hand link:** **UART1** — **TX = GPIO17**, **RX = GPIO18** (EVE side: RX receives from WALL-E TX, TX goes to WALL-E RX).

Baud rate: **115200 8N1** (see `EVE_UART_BAUD` in `config.h`).

## EVE peripherals (logical groups)

Pins are **placeholders** until your PCB is final — set real values once in `config.h`.

| Subsystem | Bus / interface | Notes |
|---|---|---|
| Dual TFT eyes | Shared **SPI** + separate **CS** per panel | One framebuffer strategy; PSRAM helps |
| ToF ×2 | **I²C** (shared SDA/SCL), address / XSHUT as needed | Short wires, pull-ups |
| Servo ×2 | **PWM** (LEDC) | Separate servo power, common GND |
| NeoPixel | **Single data GPIO**; level shifter if 5 V strip | Series resistor on data |
| DFPlayer | **UART** (often 9600 baud) | Use a **different** UART than the hand link |
| Hand ↔ WALL-E | **UART** | Dedicated; not shared with DFPlayer |

## Power

- If EVE is fed from WALL-E through the hand: add **fuse**, **bulk cap**, and a **3.3 V rail** for logic; isolate **servo** current from the MCU rail.
- If EVE is self-powered: **common GND** when mated is still mandatory.

## Firmware tree

- Source: **`eve/`** (PlatformIO). See **`eve/README.md`** for build/upload.
- Pins and feature flags: **`eve/include/config.h`** (must match your full PCB).

## Related docs

- Protocol framing: **`eve/include/eve_protocol.h`** (same message IDs as the base’s UART bridge parser).
- **Base (WALL-E brain):** optional **`main_wall_E_base/main/eve_uart_bridge.cpp`** — HTTP **`GET /api/eve/status`** for operator visibility when the hand link is wired.

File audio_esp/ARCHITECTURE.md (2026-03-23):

# WALL-E Audio / Voice / Dock Sensor Brain — Architecture

## 1. Architecture Summary

The **Audio ESP** is a dedicated ESP32-S3 module that:

- **Senses:** Left/right mics, IR dock receivers, serial voice input
- **Plays:** All WALL-E sounds via DFPlayer
- **Reports:** Status, events, dock alignment, mic direction, faults
- **Receives:** Commands from the main Base ESP32-S3 over UART

**Critical rule:** The Audio ESP **never** controls drive motors. The Base ESP32-S3 is the only board that makes movement decisions. This module only senses, interprets, plays sound, and reports.

```
┌─────────────────────────────────────────────────────────────────┐
│                     AUDIO ESP (this module)                      │
├─────────────────────────────────────────────────────────────────┤
│  DFPlayer ◄──► Audio Player    │  Left Mic ──┐                   │
│  Left Mic  ──► Mic Manager ────┼─────────────┼──► MIC_DIR        │
│  Right Mic ──►                 │  Right Mic ─┘                   │
│  Voice UART ─► Voice Commands ─┼──► VOICE_CMD events             │
│  IR Left   ──► IR Dock         │  IR Right                       │
│  IR Right  ──► Receivers ──────┼──► DOCK_IR state                │
│                               │                                 │
│  Event Router ◄──► Comms Manager ◄──► UART ◄──► Base ESP32-S3   │
└─────────────────────────────────────────────────────────────────┘
```

---

## 2. File-by-File Responsibility Map

| File | Responsibility |
|---|---|
| `audio_esp.ino` | Main entry, setup(), loop(), module init order |
| `config.h` | Feature flags, timing constants, track IDs, thresholds |
| `pins.h` | All GPIO and UART pin definitions |
| `system_state.h` | System mode enum, mode transitions, mode get/set |
| `audio_player.h` | DFPlayer init, play/stop/volume, busy state, priority |
| `mic_manager.h` | Left/right ADC read, smoothing, direction (LEFT/RIGHT/CENTER/UNKNOWN) |
| `voice_commands.h` | Serial voice parse, debounce, cooldown, emit VOICE_CMD events |
| `ir_dock_receivers.h` | Left/right IR read, debounce, states (NONE/LEFT/RIGHT/BOTH/UNSTABLE) |
| `comms_manager.h` | UART packet TX/RX, message queue, parse incoming, send outgoing |
| `event_router.h` | Route events to comms, handle incoming commands, mode changes |
| `diagnostics.h` | Print mode, mics, IR, audio, heartbeat, faults |
| `debug_log.h` | Serial debug macros (DEBUG_LOG, DEBUG_AUDIO, etc.) |

---

## 3. Pin-Planning Table

| Function | GPIO | Notes |
|---|---|---|
| **DFPlayer UART** | | |
| DFPlayer RX (ESP TX) | 17 | UART1 |
| DFPlayer TX (ESP RX) | 18 | |
| **Base link** | | ESP-NOW (no UART pins) |
| **Voice UART** (optional) | | |
| Voice RX (ESP TX) | TBD | if external voice module |
| Voice TX (ESP RX) | TBD | |
| **Left Mic** | TBD | ADC1-capable (e.g. 4) |
| **Right Mic** | TBD | ADC1-capable (e.g. 5) |
| **IR Dock Left** | TBD | Digital input, pull-up |
| **IR Dock Right** | TBD | Digital input, pull-up |
| **Status LED** | TBD | Optional, output |

**Note:** Base link uses ESP-NOW (WiFi); no UART required. Channel 11. Base sends WalleAudioCommandPacket_t; Audio ESP sends WalleAudioMicTelemPacket_t and WalleAudioStatusPacket_t.

---

## 4. State Machine Summary

| State | Description | Transitions |
|---|---|---|
| BOOT | Initializing hardware | → IDLE |
| IDLE | Ready, listening for commands | → LISTENING, PLAYING_AUDIO, DOCK_ASSIST, FAULT |
| LISTENING | Mic active, waiting for voice/events | → IDLE, VOICE_COMMAND, PLAYING_AUDIO |
| PLAYING_AUDIO | DFPlayer playing | → IDLE when done |
| DOCK_ASSIST | Dock mode, reporting IR alignment | → IDLE |
| VOICE_COMMAND | Processing voice command | → IDLE, PLAYING_AUDIO |
| FAULT | Error state (DFPlayer fail, etc.) | → IDLE on recover |

---

## 5. Packet Protocol Summary

**Format:** One message per line, terminated by `\n`. No JSON; simple `KEY:VALUE` or `KEY` text.

### Outgoing (Audio ESP → Base)

| Message | Description |
|---|---|
| `HEARTBEAT` | Periodic alive ping |
| `VOICE_CMD:STOP` | Voice said stop |
| `VOICE_CMD:COME_HERE` | Voice said come here |
| `VOICE_CMD:GO_HOME` | Voice said go home |
| `VOICE_CMD:SLEEP` | Voice said sleep |
| `VOICE_CMD:WAKE` | Voice said wake |
| `MIC_DIR:LEFT` | Louder on left |
| `MIC_DIR:RIGHT` | Louder on right |
| `MIC_DIR:CENTER` | Balanced |
| `MIC_DIR:UNKNOWN` | No clear direction |
| `DOCK_IR:NONE` | No IR detected |
| `DOCK_IR:LEFT` | Left IR only |
| `DOCK_IR:RIGHT` | Right IR only |
| `DOCK_IR:BOTH` | Both IR |
| `DOCK_IR:UNSTABLE` | Rapid switching |
| `AUDIO_BUSY:1` | Playback started |
| `AUDIO_DONE` | Playback finished |
| `MODE:IDLE` | Current mode |
| `FAULT:DFPLAYER` | DFPlayer init/play failed |
| `PONG` | Response to PING |

### Incoming (Base → Audio ESP)

| Message | Action |
|---|---|
| `PLAY:STARTUP` | Play startup track |
| `PLAY:HELLO` | Play hello/ack track |
| `PLAY:ERROR` | Play error sound |
| `PLAY:ID` | Play track by ID (e.g. PLAY:3) |
| `STOP_AUDIO` | Stop playback |
| `SET_VOLUME:20` | Set volume 0–30 |
| `ENABLE_LISTENING` | Enter LISTENING mode |
| `DISABLE_LISTENING` | Return to IDLE |
| `ENTER_DOCK_MODE` | Enter DOCK_ASSIST |
| `EXIT_DOCK_MODE` | Leave DOCK_ASSIST |
| `PING` | Reply PONG |
| `REQ_STATUS` | Send full status/diagnostics |

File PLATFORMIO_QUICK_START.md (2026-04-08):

# PlatformIO Quick Start (WALL-E)

This repo has multiple firmware targets. Open the matching folder in VS Code when building/uploading.

## 1) Master Controller (CYD)
Folder: `wall_e_master_controller`

- Open that folder in VS Code
- Select env: `cyd_esp32_2432s028`
- Build: `PlatformIO: Build`
- Upload: `PlatformIO: Upload`
- **Optional:** **SD card** (SPI: CS 5, MOSI 23, MISO 19, SCK 18) — firmware runs without it; see [wall_e_master_controller/README.md](wall_e_master_controller/README.md).

## 2) WALL-E Base Brain (ESP32-S3)
Folder: `main_wall_E_base`

- Open that folder in VS Code
- Select env: `wall_e_brain_s3`
- Build: `PlatformIO: Build`
- Upload: `PlatformIO: Upload`

## 3) Audio Brain (ESP32-S3)
Folder: `wall_e_audio`

- Open that folder in VS Code
- Select env: `wall_e_audio_s3`
- Build: `PlatformIO: Build`
- Upload: `PlatformIO: Upload`

## CLI equivalents
Run in the chosen firmware folder:

```bash
pio run
pio run -t upload
pio device list
```

## Common fixups
- If upload port is wrong, add `upload_port = COMx` to that folder's `platformio.ini`
- If monitor port is wrong, add `monitor_port = COMx`
- Close Serial Monitor before upload
- Ensure USB driver is installed (CH340 or CP210x, depending on your board)

## Note on duplicate source tree in `main_wall_E_base`
`main_wall_E_base/platformio.ini` intentionally filters sources to avoid compiling duplicate `main/main.ino` and `main/espnow_receiver.cpp` alongside top-level files.

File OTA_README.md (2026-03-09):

# WALL-E OTA (Over-the-Air) Update System

All WiFi-enabled WALL-E devices support OTA firmware updates.

## Devices & Methods

| Device | Method | Access |
|---|---|---|
| **Base** (main_wall_E_base) | ArduinoOTA + Web | `http://192.168.4.1/update` or port 3232 |
| **Controller** (wall_e_master_controller) | ArduinoOTA | Port 3232 (connects to WALL-E AP) |
| **Dock** (dock_station) | ArduinoOTA | Port 3232 (on home WiFi) |

## Quick Start

### 1. Enable OTA in platformio.ini

For each project, uncomment and set `upload_protocol` and `upload_port`:

**Base** (`main_wall_E_base/platformio.ini`):
```ini
upload_protocol = espota
upload_port = 192.168.4.1    ; AP IP, or your base's STA IP
```

**Controller** (`wall_e_master_controller/platformio.ini`):
```ini
upload_protocol = espota
upload_port = 192.168.4.2    ; Controller gets 192.168.4.x when on WALL-E AP
```

**Dock** (`dock_station/platformio.ini`):
```ini
upload_protocol = espota
upload_port = 192.168.1.xxx  ; Dock's IP on home WiFi (check router/DHCP)
```

### 2. Upload via PlatformIO

```bash
# Single device
cd main_wall_E_base
pio run -t upload

# All devices (from repo root)
./ota_build_all.ps1 -Upload     # Windows
./ota_build_all.sh upload       # Linux/macOS
```

### 3. Web Update (Base only)

1. Build base: `cd main_wall_E_base && pio run`
2. Open `http://192.168.4.1/update` in a browser (connect to WALL-E-Control AP)
3. Select the `.bin` from `.pio/build/wall_e_brain_s3/firmware.bin`
4. Click Update

## Network Setup

- **Base**: Always has AP `WALL-E-Control` (192.168.4.1). Optionally connects to home WiFi.
- **Controller**: Connects to WALL-E-Control AP for OTA (gets 192.168.4.2).
- **Dock**: Connects to home WiFi (credentials from WALL-E via ESP-NOW or `dock_config.h`).

## Hostnames (mDNS)

- `wall-e-base.local` — Base
- `wall-e-controller.local` — Controller  
- `wall-e-dock.local` — Dock

Use these instead of IPs if mDNS works on your network.

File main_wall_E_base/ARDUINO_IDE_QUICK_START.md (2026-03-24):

# Arduino IDE — WALL-E Base (recommended workflow)

Use **Arduino IDE only** for this repo unless you need PlatformIO for CI or advanced tooling. You can ignore `platformio.ini` for normal upload and edit cycles.

---

## Open the correct sketch (important)

Arduino requires: **sketch folder name = main `.ino` name** (without `.ino`).

| Path | Valid? | Notes |
|---|---|---|
| `main_wall_E_base/main/` + `main.ino` | **Yes** | **Use this.** Folder `main` matches `main.ino`. |
| `main_wall_E_base/main.ino` at repo root | **No** | Folder is `main_wall_E_base` but file is `main.ino` — names do not match; IDE may error or behave oddly. |

**What to do:** **File → Open** → select the folder  
`…/wall-e/main_wall_E_base/main`  
then open `main.ino`.

All `*.cpp` / `*.h` in that same `main/` folder are built with the sketch. Protocol headers that must live next to the sources (so Arduino finds them without extra include paths) are kept there, e.g. `audio_protocol.h`, `node_health_protocol.h` — keep them in sync with `wall_e_audio/` when you change protocols.

There is also a **root** `main_wall_E_base/main.ino` used by PlatformIO layouts; for Arduino day-to-day, treat **`main/main.ino`** as your real sketch.

---

## Board and upload

1. **Tools → Board** → ESP32 Arduino → **ESP32S3 Dev Module** (or your exact module).
2. **Tools → Port** → the Base COM port.
3. **Sketch → Upload**
4. **Tools → Serial Monitor** → **115200** baud.

---

## Libraries (Library Manager)

Install as needed for your build:

- **VL53L1X** (Pololu) — docking / ToF, if you use it  
- Others per your `*.cpp` includes (GFX, ST7789, TinyGPSPlus, MPU6050, etc.)

---

## Docking / hardware notes

- Rear obstacle pins: GPIO **20** and **47** (not 33/34 — PSRAM on many S3 boards).

---

## Boot loop `TG1WDT_SYS_RST`

1. Sketch already uses `delay(1)` / `yield()` in `loop` where applicable.  
2. If it persists: **Tools → Loop Task Stack Size** → **16384** if your core exposes it.

---

## Other WALL-E firmware folders (Arduino)

Same rule: **folder name = `.ino` name**.

| Project folder | Open this folder in Arduino | Main sketch file |
|---|---|---|
| `audio_esp/` | `audio_esp` | `audio_esp.ino` |
| `dock_station/` | `dock_station` | `dock_station.ino` |
| `wall_e_master_controller/` | `wall_e_master_controller` | `wall_e_master_controller.ino` |

Local copies of shared headers (e.g. `audio_esp/node_health_protocol.h`) exist so Arduino does not rely on `../wall_e_audio` include paths.

---

## PlatformIO

`platformio.ini` is optional for you. Developers using PlatformIO use it for unified builds; it does not affect Arduino IDE. You do **not** need to install or learn PlatformIO to work on this project.

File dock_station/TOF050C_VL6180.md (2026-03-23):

# TOF050C (VL6180X) on the dock

- **Chip:** ST VL6180X — time-of-flight, ~**20–100 mm** reliable range (ideal for “nose in slot”).
- **Power:** **3.3 V** and GND only (do not use 5 V on the sensor IC).
- **I2C:** SDA → **GPIO 9**, SCL → **GPIO 47** (change in `dock_config.h` if your board differs).
- **Address:** fixed **0x29** (no jumpers on most TOF050C boards).

## Mounting

Aim the sensor into the **docking tunnel** so Wall-E’s front surface is the main target.  
After install, open Serial and watch range (add a debug line or use `DOCK_TEST_SERIAL_CMD`): tune **`VL6180_DOCK_MIN_MM`** / **`VL6180_DOCK_MAX_MM`** in `dock_config.h` so “empty” vs “docked” readings sit outside vs inside the band.

## Firmware

- **`USE_VL6180_TOF 1`** — dock “occupied” when range is inside the mm band.
- If the sensor fails to init, the dock falls back to **`USE_SONAR`** (if 1) or **mouth obstacle** sensors.

Libraries (PlatformIO): **Adafruit VL6180X** + **Adafruit BusIO**.

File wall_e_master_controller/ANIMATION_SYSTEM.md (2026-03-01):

# Animation System Complete!

## 🎬 What's Been Added

### New Files:
1. **animation_data.h** - Simon Bluett's animation format adapted with eyebrow support

### Updated Files:
1. **motion_engine.h** - Added eyebrow servo indices
2. **motion_engine.cpp** - Full animation playback system
3. **wall_e_master_controller.ino** - Button actions for eyebrows

## 🎭 Available Animations

### ID 0: Reset/Neutral
- Returns all servos to neutral position (90°)
- 1 second duration

### ID 1: Bootup Eye Sequence
- Classic Wall-E power-up animation
- Eyes blink in sequence
- 9 frames, ~9.6 seconds total

### ID 2: Inquisitive Motion
- Full body curiosity animation
- Head movements, eye expressions, arm gestures
- 10 frames, ~18 seconds total

### ID 3: Right Eyebrow Raise (NEW)
- Quick right eyebrow lift
- 3 frames, ~0.9 seconds
- **Triggered by Joy1 button (BTN_JOY1 / Button 0)**

### ID 4: Left Eyebrow Raise (NEW)
- Quick left eyebrow lift
- 3 frames, ~0.9 seconds
- **Triggered by Joy2 button (BTN_JOY2 / Button 1)**

### ID 5: Surprised (NEW)
- Both eyebrows + eyes wide
- 3 frames, ~1.15 seconds
- Future: Could be triggered by both buttons (currently E-STOP)

## 🎮 Button Mapping

```
BTN_JOY1 (Button 0):    Right eyebrow raise → Animation 3
BTN_JOY2 (Button 1):    Left eyebrow raise  → Animation 4
Both buttons held:      E-STOP (override)
BTN_DEADMAN (Button 6): Must hold to move
Extra buttons 2-5:      Available for animations
```

## 🔧 Animation System Features

### Frame-Based Playback:
- Each frame has a hold time (milliseconds)
- Smooth crossfade between animations (300ms default)
- 2 simultaneous animation tracks
- Frame advances automatically after hold time expires

### Servo Mapping (0-100 → degrees):
```cpp
Original Format:  0-100  (50 = neutral)
Converted to:     -90° to +90° offset
Applied to:       Base position (90°)
Final range:      0° to 180°
```

### Servo Assignments:
```
Frame value: head        → SERVO_HEAD_PAN (0)
Frame value: neckTop     → SERVO_NECK_TOP (4)
Frame value: neckBottom  → SERVO_NECK_BOTTOM (5)
Frame value: eyeRight    → SERVO_EYE_RIGHT (3)
Frame value: eyeLeft     → SERVO_EYE_LEFT (2)
Frame value: armLeft     → SERVO_LEFT_ARM (6)
Frame value: armRight    → SERVO_RIGHT_ARM (7)
Frame value: eyebrowRight → SERVO_EYEBROW_RIGHT (8)  NEW!
Frame value: eyebrowLeft  → SERVO_EYEBROW_LEFT (9)   NEW!
```

### Smart Blending:
- **Joystick overrides animations per-axis**
  - Joy1_X active → head pan animation muted
  - Joy1_Y active → head tilt animation muted
  - Other servos continue animating normally
  
- **Animations continue in background**
  - If joystick releases, animation resumes seamlessly
  - No restart needed

- **-1 values = servo disabled**
  - Frame can control some servos, leave others unchanged
  - Example: Eyebrow animation doesn't affect head/arms

## 📝 Adding New Animations

### Step 1: Define Frames
```cpp
const AnimationFrame anim6_frames[] PROGMEM = {
  // time, head, nT, nB, eyeR, eyeL, armL, armR, ebrR, ebrL
  {1000,   60, -1, -1,  -1,   -1,   80,   80,   -1,   -1},  // Look right, arms up
  {1000,   40, -1, -1,  -1,   -1,   80,   80,   -1,   -1},  // Look left, arms still up
  {1000,   50, -1, -1,  -1,   -1,   40,   40,   -1,   -1}   // Center, arms down
};
```

### Step 2: Add to Library
```cpp
const AnimationDef animationLibrary[] PROGMEM = {
  // ... existing animations ...
  {"LookAround", anim6_frames, sizeof(anim6_frames)/sizeof(AnimationFrame)}
};
```

### Step 3: Trigger from Code
```cpp
if (btn.pressed[BTN_EXTRA1]) {
  motionTriggerAnimation(6);  // Play new animation
}
```

## 🎯 Testing

### Upload and Test:
1. **Hold Button 6 (deadman)**
2. **Press Joy1 button (Button 0)** → Right eyebrow should raise
3. **Press Joy2 button (Button 1)** → Left eyebrow should raise
4. **Move Joy1 while animation plays** → Head follows joystick, other servos continue animating

### Expected Serial Output:
```
[Motion] Engine initialized
[Action] Right eyebrow raise
[Motion] Playing animation 3: EyebrowRight (3 frames on track 1)
[Action] Left eyebrow raise
[Motion] Playing animation 4: EyebrowLeft (3 frames on track 1)
```

## 🔌 Base Controller Integration

The Base needs to:
1. Receive `pkt.servoTargets[0-9]` from ControlPacket
2. Map to physical servos:

```cpp
// Example servo mapping on Base:
Servo servos[10];

// In setup():
servos[0].attach(PIN_HEAD_PAN);
servos[1].attach(PIN_HEAD_TILT);
servos[2].attach(PIN_EYE_LEFT);
servos[3].attach(PIN_EYE_RIGHT);
servos[4].attach(PIN_NECK_TOP);
servos[5].attach(PIN_NECK_BOTTOM);
servos[6].attach(PIN_ARM_LEFT);
servos[7].attach(PIN_ARM_RIGHT);
servos[8].attach(PIN_EYEBROW_RIGHT);  // NEW
servos[9].attach(PIN_EYEBROW_LEFT);   // NEW

// In ESP-NOW receive callback:
for (int i = 0; i < 10; i++) {
  servos[i].write(pkt->servoTargets[i]);
}
```

## 🎉 What Works Now

✅ **Tank Drive** (Joy2)
✅ **Head Control** (Joy1, velocity-based)
✅ **Eyebrow Animations** (Joy1/Joy2 buttons)
✅ **Full Animation System** (6 pre-loaded animations)
✅ **Smart Blending** (joystick overrides, per-axis)
✅ **Deadman Safety** (Button 6)
✅ **E-STOP** (both joystick buttons)
✅ **Dual Animation Tracks** (crossfade support)

## 🚀 Next Steps

### Available Enhancements:
1. **Map extra buttons** (2-5) to animations (Bootup, Inquisitive, etc.)
2. **Create more animations** (wave, dance, sleep, etc.)
3. **Profile system** (different button mappings per profile)
4. **UI animation triggers** (touchscreen buttons for animations)
5. **Animation sequences** (chain multiple animations)

---

**Your WALL-E now has a complete animation system compatible with Simon Bluett's original format, plus new eyebrow control!** 🤖✨

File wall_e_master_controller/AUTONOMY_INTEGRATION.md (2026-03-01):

// ============================================================
//  WALL-E AUTONOMOUS MODE - INTEGRATION GUIDE
// ============================================================

## INTEGRATION STEPS

### 1. Add to wall_e_master_controller.ino

At top with other includes:
```cpp
#include "autonomy_engine.h"
#include "sonar_sensor.h"
#include "compass_sensor.h"
#include "gps_module.h"
```

In setup():
```cpp
// After profileInit()
autonomyInit();
```

In loop(), AFTER joystick read but BEFORE packetUpdate:
```cpp
// Check if joystick is active (for autonomy override)
bool joystickActive = joy.active[JOY2_X] || joy.active[JOY2_Y];
autonomySetJoystickOverride(joystickActive);

// Update sensors
sonarUpdate(now);
compassUpdate(now);
gpsUpdate(now);

// Update autonomy engine
autonomyUpdate(now);

// Get autonomy drive output if enabled
if (autonomyIsEnabled() && !joystickActive) {
  const AutoContext* ctx = autonomyGetContext();
  // Apply autonomous drive commands
  // (autonomy engine modifies DriveState internally)
}
```

### 2. Add PAGE_AUTONOMY to ui_draw.h

In Page enum:
```cpp
enum Page {
  PAGE_DRIVE,
  PAGE_BEHAVIOUR,
  PAGE_SYSTEM,
  PAGE_PROFILE,
  PAGE_SERVO_EDITOR,
  PAGE_SERVO_TEST,
  PAGE_AUTONOMY        // NEW
};
```

### 3. Add Autonomy UI Page (ui_draw.cpp)

```cpp
void uiDrawPageAutonomy(void) {
  if (!g_tft) return;
  g_tft->fillScreen(C_BG);
  
  // Grid
  for (int x = 0; x < SCREEN_W; x += GRID_SPACING)
    g_tft->drawFastVLine(x, 0, SCREEN_H, C_GRID);
  for (int y = 0; y < SCREEN_H; y += GRID_SPACING)
    g_tft->drawFastHLine(0, y, SCREEN_W, C_GRID);
  
  // Top bar
  g_tft->fillRect(0, 0, SCREEN_W, TOP_BAR_HEIGHT, C_BG_DARK);
  g_tft->setTextColor(C_WHITE, C_BG_DARK);
  g_tft->setTextSize(2);
  g_tft->drawString("Autonomy", 10, 6);
  
  // Enable/Disable toggle
  bool enabled = autonomyIsEnabled();
  g_tft->fillRect(200, 50, 100, 32, enabled ? C_GREEN : C_RED);
  g_tft->setTextColor(C_WHITE, enabled ? C_GREEN : C_RED);
  g_tft->setTextSize(1);
  g_tft->drawString(enabled ? "ENABLED" : "DISABLED", 215, 60);
  
  // Current state
  const char* stateName = autonomyGetStateName();
  g_tft->setTextColor(C_ACCENT, C_BG);
  g_tft->drawString("State:", 16, 56);
  g_tft->setTextColor(C_WHITE, C_BG);
  g_tft->drawString(stateName, 60, 56);
  
  // Sonar distance
  const AutoContext* ctx = autonomyGetContext();
  char buf[32];
  snprintf(buf, sizeof(buf), "Sonar: %.1fcm", ctx->detectedDistance);
  g_tft->setTextColor(C_ACCENT, C_BG);
  g_tft->drawString(buf, 16, 80);
  
  // Heading
  const LocationState* loc = autonomyGetLocation();
  snprintf(buf, sizeof(buf), "Heading: %.0f°", loc->heading);
  g_tft->drawString(buf, 16, 104);
  
  // GPS status
  if (loc->gpsValid) {
    snprintf(buf, sizeof(buf), "GPS: %.6f,%.6f", loc->latitude, loc->longitude);
  } else {
    snprintf(buf, sizeof(buf), "GPS: No fix");
  }
  g_tft->drawString(buf, 16, 128);
  
  // Personality
  const Personality* pers = autonomyGetPersonality();
  g_tft->setTextSize(1);
  g_tft->setTextColor(C_TEXT_DIM, C_BG);
  snprintf(buf, sizeof(buf), "Curiosity:%.1f Bravery:%.1f", pers->curiosityLevel, pers->braveryLevel);
  g_tft->drawString(buf, 16, 160);
  snprintf(buf, sizeof(buf), "Energy:%.1f Random:%.1f", pers->energyLevel, pers->randomness);
  g_tft->drawString(buf, 16, 176);
  
  // Back button
  g_tft->fillRect(SCREEN_W / 2 - 50, BOTTOM_BAR_Y + 4, 100, 32, C_ACCENT);
  g_tft->setTextColor(C_BG, C_ACCENT);
  g_tft->drawString("Back", SCREEN_W / 2 - 18, BOTTOM_BAR_Y + 14);
}
```

In uiDrawCurrentPage():
```cpp
case PAGE_AUTONOMY:
  uiDrawPageAutonomy();
  break;
```

### 4. Add Touch Zones (touch_input.h)

```cpp
enum TouchZone {
  // ... existing zones ...
  TOUCH_ZONE_NAV_AUTONOMY,
  TOUCH_ZONE_AUTONOMY_TOGGLE
};
```

### 5. Add Touch Handlers (touch_input.cpp)

In touchGetZone():
```cpp
// Autonomy page
if (page == 6) {  // PAGE_AUTONOMY
  // Toggle button (200, 50, 100x32)
  if (screenX >= 200 && screenX <= 300 && screenY >= 50 && screenY <= 82) {
    return TOUCH_ZONE_AUTONOMY_TOGGLE;
  }
}

// System page - add Autonomy button
if (page == 2) {
  // Autonomy button at (16, 140)
  if (screenY >= 140 && screenY <= 172 && screenX >= 16 && screenX <= 116) {
    return TOUCH_ZONE_NAV_AUTONOMY;
  }
}
```

In wall_e_master_controller.ino loop():
```cpp
if (zone == TOUCH_ZONE_NAV_AUTONOMY) {
  g_currentPage = PAGE_AUTONOMY;
  g_needStaticRedraw = true;
  playUISound(SOUND_CLICK);
}

if (zone == TOUCH_ZONE_AUTONOMY_TOGGLE) {
  autonomySetEnabled(!autonomyIsEnabled());
  g_needStaticRedraw = true;
  playUISound(SOUND_MODE_CHANGE);
}
```

### 6. Apply Personality from Profile

In profiles.cpp profileApply():
```cpp
// Apply autonomous personality
Personality pers;
pers.curiosityLevel = p->autonomyCuriosity;
pers.braveryLevel = p->autonomyBravery;
pers.energyLevel = p->autonomyEnergy;
pers.randomness = p->autonomyRandomness;
autonomySetPersonality(&pers);
autonomySetEnabled(p->autonomyEnabled);
```

### 7. Hardware Connections

**Sonar (HC-SR04 or similar):**
- Trigger Pin: GPIO 26
- Echo Pin: GPIO 27
- VCC: 5V
- GND: GND

**Compass (HMC5883L or QMC5883L):**
- SDA: GPIO 21 (shared I2C)
- SCL: GPIO 22 (shared I2C)
- VCC: 3.3V
- GND: GND

**GPS Module (NEO-6M/7M/8M):**
- RX: GPIO 16 (UART2 TX)
- TX: GPIO 17 (UART2 RX)
- VCC: 3.3V or 5V (check module)
- GND: GND

### 8. Required Libraries

Add to platformio.ini or Arduino IDE:
```
TinyGPSPlus @ ^1.0.3
```

### 9. Safety Features

- Sonar timeout (2s) stops autonomy
- Compass failure disables heading features
- Joystick ALWAYS overrides autonomy
- E-STOP immediately disables autonomy
- Deadman button NOT required for autonomy (only for manual drive)

### 10. Behavior Summary

**AUTO_IDLE:** Waiting, idle behaviours only
**AUTO_SCAN:** Neck sweeps left-right, capturing sonar readings
**AUTO_EVALUATE:** Processes scan results, decides action
**AUTO_APPROACH:** Moves toward detected object
**AUTO_INVESTIGATE_HEIGHT:** Random vertical investigation (1-10 levels)
**AUTO_REACT:** Close-range reaction (eyebrows, sounds)
**AUTO_AVOID:** Backs away from obstacle
**AUTO_ORIENT:** Rotates to target compass heading
**AUTO_EXPLORE_LOOP:** Random wandering with compass-based navigation

## COMPILE ORDER

1. Compile sonar_sensor.cpp
2. Compile compass_sensor.cpp
3. Compile gps_module.cpp
4. Compile autonomy_engine.cpp
5. Update profiles.cpp
6. Update ui_draw.cpp
7. Update touch_input.cpp
8. Update wall_e_master_controller.ino

All non-blocking. All safe. Joystick always wins.

THIS IS A CHARACTER, NOT A ROBOT.

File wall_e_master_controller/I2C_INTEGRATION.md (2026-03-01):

# I2C Joystick + Button Integration

## Added Files

1. **i2c_devices.h/cpp** - I2C bus init and scanner
2. **ads1115_input.h/cpp** - ADS1115 analog joystick processing
3. **sx1509_input.h/cpp** - SX1509 GPIO expander button handling

## Integration

### Hardware

```
ADS1115 (0x48):
  A0 → Joy1_X (Head Pan, future)
  A1 → Joy1_Y (Head Tilt, future)
  A2 → Joy2_X (Turn)
  A3 → Joy2_Y (Throttle)

SX1509 (0x3E):
  Pin 0 → BTN_JOY1 (Right eyebrow)
  Pin 1 → BTN_JOY2 (Left eyebrow)
  Pin 2-5 → BTN_EXTRA1-4 (Programmable)

I2C Bus:
  SDA = GPIO27
  SCL = GPIO22
```

### Software Changes

**wall_e_master_controller.ino:**

- Added includes for I2C modules
- `setup()` now calls:
  - `i2cInit()` - Initialize I2C bus
  - `i2cScan()` - Scan for devices
  - `ads1115Init()` - Calibrate joysticks (keep centered)
  - `sx1509Init()` - Configure buttons

- `loop()` now:
  - Calls `ads1115Update()` + `sx1509Update()` each cycle
  - **Physical joystick overrides touch input**
  - Adds button action: **Both joystick buttons = E-STOP**

## Features

### Joystick Processing

- **Auto-calibration** on boot (100 samples, keep centered)
- **Deadzone** (default 8%)
- **Exponential curve** (default 30% cubic)
- **Tank-drive mixing** (Joy2_Y = throttle, Joy2_X = turn)

### Button Handling

- **Debouncing** (30ms)
- **Edge detection** (pressed/released flags)
- **Held state** tracking

## Tuning

Add to your system settings page:

```cpp
setJoystickDeadzone(0.12f);  // 12% deadzone
setJoystickExpo(0.5f);       // 50% cubic response
setJoystickMaxOutput(0.8f);  // Limit to 80% speed
```

## Required Libraries

1. **Adafruit_ADS1X15** (Install via Library Manager)
2. **SparkFun SX1509** (Install via Library Manager)

## Testing

Upload and open Serial Monitor (115200 baud):

1. Boot should show:
   ```
   [I2C] Init OK (400kHz)
   --- I2C Bus Scan ---
     [0x48] found (ADS1115)
     [0x3E] found (SX1509)
   [ADS1115] ✓ Calibration complete
   [SX1509] ✓ Configured
   ```

2. Move joysticks - should see drive commands
3. Press buttons - should see `[Button] BTNx pressed`

## Priority System

**Control Authority (highest to lowest):**

1. Both joystick buttons held → E-STOP
2. Touch E-STOP zone → E-STOP
3. Physical joystick active → Physical control
4. Touch joystick active → Touch control
5. Timeout (200ms no input) → STOP

---

✅ **Your existing controller now supports dual input!**

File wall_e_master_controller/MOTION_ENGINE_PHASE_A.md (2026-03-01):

# Motion Engine Implementation - Phase A Complete

## ✅ What's Been Added

### New Files Created:
1. **motion_engine.h** - Motion system interface
2. **motion_engine.cpp** - 9-servo blending engine

### Updated Files:
1. **protocol.h** - Added 10 servo targets to ControlPacket
2. **wall_e_master_controller.ino** - Integrated motion engine + head control
3. **packet_control.cpp** - Includes servo targets in packets

## 🎮 Features Implemented

### 1. **Head Control (Joy1)**
```cpp
Joy1_X (Left stick X) → Head Pan (velocity-based)
Joy1_Y (Left stick Y) → Head Tilt (velocity-based)
```

- **Velocity integration**: Joystick controls rotation speed, not position
- **60°/second** at full stick deflection
- **Automatic muting**: When joystick active, animations don't affect head
- **Smooth return**: When centered, animations can take over

### 2. **9-Servo Motion System**
```
SERVO_HEAD_PAN       (0) - Controlled by Joy1_X
SERVO_HEAD_TILT      (1) - Controlled by Joy1_Y
SERVO_EYE_LEFT       (2) - Future: eyebrow/eye control
SERVO_EYE_RIGHT      (3) - Future: eyebrow/eye control
SERVO_NECK_TOP       (4) - Future: neck articulation
SERVO_NECK_BOTTOM    (5) - Future: neck articulation
SERVO_LEFT_ARM       (6) - Future: arm gestures
SERVO_RIGHT_ARM      (7) - Future: arm gestures
SERVO_LEFT_TRACK     (8) - Optional servo track
SERVO_RIGHT_TRACK    (9) - Optional servo track
```

### 3. **Offset-Based Blending**
Each servo has three layers:
```cpp
Final = BasePosition + AnimationOffset*(1-JoyInfluence) + JoystickOffset
```

- **Base Position**: Neutral/home position (90° default)
- **Animation Offset**: Contribution from animation playback
- **Joystick Offset**: Direct control from physical joystick
- **Joystick Influence**: 0.0-1.0, automatically calculated from stick movement

### 4. **Animation Infrastructure**
- **2 animation tracks** with crossfade (300ms default)
- **Per-axis muting**: Joystick on one axis doesn't stop other animations
- **Smooth transitions**: 20% smoothing factor prevents servo jitter
- **Emergency stop**: E-STOP neutralizes all servos instantly

### 5. **Safety Features**
- **E-STOP stops servos** - Both joystick buttons → all servos to neutral
- **Deadman button applies to everything** - No movement without Button 6 held
- **Servo limits**: All outputs clamped 0-180°
- **Velocity limiting**: Head can't move faster than 60°/s

## 📊 Control Flow

```
Loop Iteration:
1. Update I2C (joysticks + buttons)
2. motionSetHeadPanVelocity()     ← Joy1_X
3. motionSetHeadTiltVelocity()    ← Joy1_Y  
4. joystickToDriveState()         ← Joy2 for tank
5. motionUpdate()                 ← Blend all layers
6. motionGetServoTargets()        ← Get final positions
7. packetUpdate()                 ← Send to Base (50Hz)
```

## 🔌 Base Controller Integration Required

The **Base ESP32 now needs to:**
1. Receive expanded ControlPacket (now includes 10 servo bytes)
2. Read `pkt.servoTargets[0-9]`
3. Drive servos with `servo.write(pkt.servoTargets[i])`

### Example Base Code Update:
```cpp
// In espnow_receiver.cpp onRecv():
typedef struct __attribute__((packed)) {
  int8_t   leftSpeed;
  int8_t   rightSpeed;
  uint8_t  driveMode;
  uint8_t  behaviourMode;
  uint8_t  action;
  uint16_t systemFlags;
  uint8_t  servoTargets[10];  // NEW!
} ControlPacket;

// After existing motor control:
for (int i = 0; i < 10; i++) {
  servos[i].write(p->servoTargets[i]);
}
```

## 🎯 Current Behavior

### Head Control:
- **Joy1 centered** → Head stays at current position
- **Joy1 left** → Head pans left continuously
- **Joy1 up** → Head tilts up continuously
- **Joy1 diagonal** → Combined pan + tilt
- **Release stick** → Head stops moving (holds position)

### Servo Targets in Packet:
```
servoTargets[0] = 90 + Joy1_X_integrated  (Head Pan)
servoTargets[1] = 90 + Joy1_Y_integrated  (Head Tilt)
servoTargets[2-9] = 90  (Neutral, awaiting animations)
```

## 📝 Next Steps (Not Yet Implemented)

### Phase B - Animations:
- Load animation data (keyframes)
- Playback system with time interpolation
- Track crossfading
- Animation library (idle, scan, lookabout, etc.)

### Phase C - Button Actions:
- Joy1 button → Right eyebrow raise
- Joy2 button → Left eyebrow raise
- Both buttons → Surprised macro (already triggers E-STOP)
- Extra buttons → Programmable per profile

### Phase D - Profile System:
- Kid/Demo/Advanced modes
- Per-profile servo tuning
- Button mapping per profile
- Preferences storage

## 🧪 Testing

### Upload and Test Head Control:
1. Upload to controller
2. Hold Button 6 (deadman)
3. Move Joy1 (left stick):
   - Left/Right → Head should pan
   - Up/Down → Head should tilt
   
### Monitor Serial Output:
```
[Motion] Engine initialized
[Motion] (no messages during normal operation)
[Motion] EMERGENCY STOP  (when both joystick buttons pressed)
```

### Check Packet in Base Serial:
```
Servo 0: 75   ← Head panned left
Servo 1: 105  ← Head tilted up
Servo 2-9: 90 ← Neutral
```

## 🎉 Status

✅ **Phase A Complete**: Head control + motion engine foundation

The controller now sends complete servo commands alongside drive commands. The Base needs a simple update to receive and apply the 10 servo positions.

**This is a major milestone!** Your WALL-E now has:
- Tank drive (Joy2)
- Head control (Joy1)
- Future-ready animation system
- Professional safety features
- 50Hz deterministic control

---

Ready for Phase B (animations) or Phase C (button actions)?

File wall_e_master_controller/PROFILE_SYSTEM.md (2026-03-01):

# Profile System Complete!

## 🎯 3 Profiles Implemented

### Profile 0: Kid Mode 👶
**Safe, slow, limited**
- 50% max speed
- 15% deadzone (large)
- 50% expo (very gentle)
- Slow head movements (0.5x)
- Only animations 0, 1, 2 allowed
- 3 second auto-stop timeout
- **Button Mapping**:
  - Button 2 → Bootup animation
  - Button 3 → Inquisitive animation
  - Button 4 → Happy sound
  - Button 7 → E-STOP

### Profile 1: Demo Mode 🎭
**Balanced for demonstrations** (DEFAULT)
- 80% max speed
- 8% deadzone (normal)
- 20% expo (light)
- Normal head movements (1.0x)
- All animations allowed
- 5 second auto-stop timeout
- **Button Mapping**:
  - Button 2 → Bootup animation
  - Button 3 → Inquisitive animation
  - Button 4 → Surprised animation
  - Button 5 → Sound effect
  - Button 6 **(was deadman, now also)** → Profile cycle

### Profile 2: Advanced Mode ⚡
**Full control, no limits**
- 100% max speed
- 3% deadzone (minimal)
- 0% expo (linear, fastest response)
- Fast head movements (1.5x)
- All animations allowed
- No auto-stop timeout
- **Button Mapping**:
  - Button 2 → Bootup animation
  - Button 3 → Inquisitive animation
  - Button 4 → Surprised animation
  - Button 5 → Reset animation
  - Button 6 → Profile cycle

## 🎮 How to Use

### Switching Profiles:
**Option 1**: Press Button 6 (cycles through profiles)
**Option 2**: Via code:
```cpp
profileSet(PROFILE_KID);      // Set Kid mode
profileSet(PROFILE_DEMO);     // Set Demo mode
profileSet(PROFILE_ADVANCED); // Set Advanced mode
```

### Current Profile:
```cpp
Profile* p = profileGet();
Serial.println(p->name);  // Prints "Kid", "Demo", or "Advanced"
```

## 💾 Automatic Saving

- **Profile selection is saved to flash** (ESP32 Preferences)
- **Persists through power cycles**
- **Loads automatically on boot**

## 🔧 Features Implemented

### Per-Profile Settings:
✅ Joystick deadzone (0.03 - 0.15)
✅ Joystick expo curve (0.0 - 0.5)
✅ Max speed limit (0.5 - 1.0)
✅ Head sensitivity multiplier (0.5 - 1.5)
✅ Servo speed limits
✅ Animation permissions (allow list)
✅ Button action mappings
✅ Safety timeouts

### Button Action Types:
- `BTN_ACTION_NONE` - Disabled
- `BTN_ACTION_ANIMATION` - Trigger animation by ID
- `BTN_ACTION_ESTOP` - Emergency stop
- `BTN_ACTION_PROFILE_CYCLE` - Switch profiles
- `BTN_ACTION_SOUND` - Play UI sound
- `BTN_ACTION_CUSTOM` - Future expansion

### Safety Features:
- Animation permissions per profile (Kid mode restricted)
- Auto-stop timeout (Kid: 3s, Demo: 5s, Advanced: disabled)
- Deadman button required (all profiles)
- Speed limiting per profile

## 📊 Profile Comparison

| Feature | Kid | Demo | Advanced |
|---|-----|---|---|
| Max Speed | 50% | 80% | 100% |
| Deadzone | 15% | 8% | 3% |
| Expo | 50% | 20% | 0% |
| Head Speed | 0.5x | 1.0x | 1.5x |
| Animations | 3 only | All | All |
| Auto-Stop | 3s | 5s | None |
| Response | Gentle | Balanced | Instant |

## 🎯 Current Behavior

### On Boot:
```
[Profile] Loaded profile: 1 (Demo)
[Profile] Applied: Demo
  Deadzone: 0.08, Expo: 0.20, MaxSpeed: 0.80
  HeadSens: 1.00, ServoLimit: 1.00
```

### Button Press:
```
[Profile] Button 0 → Animation 1
[Motion] Playing animation 1: Bootup (9 frames on track 1)
```

### Profile Cycle:
```
[Profile] Switched to: Advanced
[Profile] Applied: Advanced
  Deadzone: 0.03, Expo: 0.00, MaxSpeed: 1.00
  HeadSens: 1.50, ServoLimit: 1.00
```

## 🔮 Future Enhancements (Not Yet Implemented)

### Profile Selection UI:
- Touchscreen profile selector
- Visual indication of current profile
- Profile details on screen

### Servo Tuning UI:
- Per-servo calibration screens
- Min/max position adjustment
- Speed curve tuning

### Advanced Button Programming:
- Touchscreen button mapper
- Animation preview
- Custom action sequences

## 🧪 Testing

### Upload and Test:
1. **Default profile = Demo** (loads from flash)
2. **Press Button 2** → Bootup animation plays
3. **Press Button 3** → Inquisitive animation plays
4. **Hold Button 6** → Cycles to Advanced mode
5. **Notice faster response** → 100% speed, linear
6. **Power cycle** → Profile persists!

### Serial Output:
```
[Profile] Loaded profile: 1 (Demo)
[Profile] Applied: Demo
[Profile] Button 0 → Animation 1
[Profile] Switched to: Advanced
[Profile] Saved to flash
```

## 📝 Adding Custom Profiles

Edit `profiles.cpp` to add Profile 3:

```cpp
Profile profiles[PROFILE_COUNT] = {
  // ... existing profiles ...
  {
    .name = "Custom",
    .joystickDeadzone = 0.05f,
    .joystickExpo = 0.1f,
    .joystickMaxSpeed = 0.9f,
    // ... your settings ...
  }
};
```

Update `PROFILE_COUNT` in `profiles.h`:
```cpp
#define PROFILE_COUNT 4
```

---

## 🎉 Status Update

✅ **Motion Engine** (Head control + 9 servos)
✅ **Animation System** (6 animations + Simon Bluett format)
✅ **Profile System** (Kid/Demo/Advanced modes)
✅ **Button Mapping** (Per-profile actions)
✅ **Preferences Storage** (Persistent across reboots)

**Your WALL-E controller now has a complete profile system!** 🤖✨

The only remaining TODO is the **Profile Selection UI** which would add touchscreen controls for switching profiles and viewing settings.

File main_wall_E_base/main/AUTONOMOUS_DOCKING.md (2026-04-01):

# Autonomous Docking System

Production-quality docking behaviour for life-size WALL-E.

## State Machine

| State | Description |
|---|---|
| **IDLE**  | Normal operation. Transitions to SEARCH when battery < 20% or on manual request. |
| **SEARCH**| Rotate slowly, listen for ESP-NOW beacon (RSSI) or IR beacon signals. |
| **ALIGN** | Steer using left/right IR receivers until `|left - right| < threshold`. |
| **APPROACH** | Drive forward with ToF-based speed: >200mm normal, 120–200 slow, 60–120 crawl, <60 stop → DOCKED. |
| **DOCKED** | IR beam confirms arrival; send REQUEST_CHARGE via ESP-NOW. |
| **CHARGING** | Motors off, stationary. |

## Sensors

- **VL53L1X ToF** (I2C) — approach distance and dock arrival
- **Two IR TX on WALL-E** (`dock_ir_transmitters`) + **two IR RX on dock** → **`ir_align_hint`** on beacon for ALIGN
- **ESP-NOW** — beacon RSSI and `dock_id`

## Configuration

`main/dock_config.h` — set `USE_AUTONOMOUS_DOCKING`:
- `1` — new autonomous docking FSM (default)
- `0` — legacy dock_homing (RSSI-based)

`main/autonomous_docking.h` — thresholds:
- `DOCK_BATTERY_LOW_PCT` 20
- `DOCK_TOF_NORMAL_MM` 200, `DOCK_TOF_SLOW_MM` 120, `DOCK_TOF_CRAWL_MM` 60
- `DOCK_IR_ALIGN_THRESHOLD` 20

## Files

| File | Purpose |
|---|---|
| `autonomous_docking.cpp/h` | State machine, navigation logic |
| `dock_ir_transmitters.cpp/h` | ~38 kHz IR toward dock |
| `dock_controller.cpp/h` | `dockControllerSendRequestCharge()` |
| `dock_config.h` | USE_AUTONOMOUS_DOCKING switch |

## Dock Station

When WALL-E sends `DOCK_CMD_REQUEST_CHARGE` and the dock accepts arrival, the dock enables the charging MOSFET. See `dock_station/dock_state.cpp`.

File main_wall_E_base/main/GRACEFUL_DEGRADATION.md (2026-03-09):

# Graceful Degradation Implementation - Feb 24, 2026

## Goal
WALL-E should boot and operate even when optional sensors are not present.

## Implementation Strategy

### 1. Fail-Safe Initialization
All sensor init functions now return `bool`:
- `true` = sensor initialized successfully
- `false` = sensor not present/failed, continue without it

### 2. Main.ino Changes
```cpp
if (!sonarInit()) {
  Serial.println("[Sonar] ⚠️  Not available - continuing without");
} else {
  Serial.println("[Sonar] ✓ Ready");
}
```

### 3. Sensor Behavior Without Hardware

| Sensor | Without Hardware | Autonomy Impact |
|---|---|---|
| **Sonar** | Always returns `0cm`, `valid=false` | No obstacle detection, exploration continues |
| **Compass** | Returns heading `0°`, `valid=false` | No orientation awareness, wander mode affected |
| **GPS** | No fix, `lat/lon = 0`, `valid=false` | No waypoint navigation, no return-home |
| **IMU** | Already shows "not found" and continues | No tilt safety, basic operation unaffected |

### 4. Behavioral Engines
All behavioral engines (personality, emotion, interest, memory, return home) initialize with default values regardless of sensor availability:

- **Personality**: Uses saved preferences or defaults
- **Emotion**: Starts in CALM state
- **Interest**: Starts at 0
- **Memory**: Empty history, no home set
- **Return Home**: Idle until home position is set

### 5. Autonomy Engine Degraded Modes

#### Full Sensor Suite
- Sonar + Compass + GPS → Full autonomous exploration with waypoints

#### Missing GPS
- Sonar + Compass → Local exploration, no waypoint navigation

#### Missing Compass  
- Sonar only → Simple forward/backward exploration

#### Missing All Sensors
- Autonomous mode effectively disabled
- Manual control via CYD always works

### 6. WebUI Status
The WebUI `/api/autonomy` endpoint reports sensor validity:
```json
{
  "sonarValid": false,
  "compassValid": false,
  "gpsValid": false,
  "heading": 0.0,
  "sonar": 0.0
}
```

## Boot Sequence (Current)
```
[WALL-E] Starting...
[Motors] Initialised
[Display] ST7789 240x240 initialised
[Servos] PCA9685 initialised at 0x40, 9 channels
[IMU] MPU6050 not found — check wiring and I2C address
[IMU] Init complete
[Autonomy] Initializing sensors...
[Sonar] ✓ Ready  (or ⚠️ Not available)
[Compass] ⚠️ Not available - continuing without
[GPS] ⚠️ Not available - continuing without
[Waypoint] ✓ Ready
[Autonomy] Initializing behavioral engines...
[Personality] ✓ Ready
[Emotion] ✓ Ready
[Interest] ✓ Ready
[Memory] ✓ Ready
[ReturnHome] ✓ Ready
[Autonomy] ✓ Engine ready
[Battery] Initialised
[WiFi] AP mode: WALL-E-xxxx
[WebServer] Started on http://192.168.4.1
[ESP-NOW] Receiver initialised
[WALL-E] Ready
```

## Safety Features

### Watchdog Protection
- Each init function is non-blocking
- No long delays or blocking I2C waits
- ESP32 watchdog won't trigger

### Sensor Validity Checks
All update functions check initialization status:
```cpp
void sonarUpdate(uint32_t now) {
  // Safe to call even if init failed
  if (!s_initialized) return;
  // ...
}
```

### Autonomous Override
- Joystick ALWAYS has priority
- If sensors fail during operation, autonomy safely stops
- Manual control never affected by sensor failures

## Testing Checklist

### Minimal Configuration (No External Sensors)
- [ ] WALL-E boots successfully
- [ ] WebUI accessible at 192.168.4.1
- [ ] CYD controller connects via ESP-NOW
- [ ] Manual drive works perfectly
- [ ] Servos respond to CYD inputs
- [ ] Autonomous mode can be enabled (but does nothing useful)

### With Sonar Only
- [ ] Sonar readings shown in WebUI
- [ ] Basic obstacle awareness works
- [ ] Exploration possible without GPS/Compass

### With Full Sensor Suite
- [ ] All sensors report ✓ Ready
- [ ] Full autonomous exploration works
- [ ] Waypoint navigation functional
- [ ] Return-to-home works when battery low

## Hardware Requirements

### Minimum (Core Functionality)
- ESP32-S3 Base Brain ✓
- L298N Motor Driver ✓
- ST7789 Display ✓
- PCA9685 Servo Driver ✓

### Optional (Enhanced Autonomy)
- HC-SR04 Sonar (GPIO 26/27)
- HMC5883L/QMC5883L Compass (I2C 0x1E/0x0D)
- NEO-6M GPS Module (UART2)
- MPU6050 IMU (I2C 0x68)

## Next Steps
1. Upload and verify boot sequence completes
2. Test WebUI access
3. Test CYD manual control
4. Add sensors one-by-one to verify each works
5. Test full autonomous mode with all sensors

## Debug Commands
```
ESP.getFreeHeap()      // Check available RAM
esp_get_free_heap_size() // Alt heap check
esp_task_wdt_reset()   // Manual watchdog feed (if needed)
```

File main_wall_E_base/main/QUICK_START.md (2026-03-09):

# WALL-E Behavioral Brain - Quick Reference

## 🚀 Upload This Now
`main/main.ino` - Now has graceful sensor init (continues even if sensors fail)

## 📺 Expected Boot Output
```
[WALL-E] Starting...
[Motors] Initialised
[Display] ST7789 240x240 initialised
[Servos] PCA9685 initialised
[IMU] MPU6050 not found — check wiring
[IMU] Init complete
[Autonomy] Initializing sensors...
[Sonar] ✓ Ready
[Compass] ⚠️  Not available - continuing without
[GPS] ⚠️  Not available - continuing without
[Waypoint] ✓ Ready
[Autonomy] Initializing behavioral engines...
[Personality] ✓ Ready
[Emotion] ✓ Ready
[Interest] ✓ Ready
[Memory] ✓ Ready
[ReturnHome] ✓ Ready
[Autonomy] ✓ Engine ready
[WALL-E] Ready ✅
```

## 🎮 How to Enable Autonomy

### Option 1: CYD Controller
1. Navigate to **System** page
2. Tap large **"AUTO MODE"** button (turns GREEN)
3. Wall-E starts exploring!

### Option 2: WebUI
1. Open browser: `http://192.168.4.1`
2. Click **"Autonomy"** tab
3. Click **"Enable"** button
4. Watch live telemetry

## 🧠 What Each Engine Does

| Engine | Purpose | Output |
|---|---|---|
| **Personality** | WHO Wall-E is | curiosity, bravery, energy, randomness |
| **Emotion** | HOW Wall-E feels | Calm/Curious/Excited/Nervous/LowPower |
| **Interest** | WHAT interests Wall-E | 0-100 interest level in objects |
| **Memory** | WHAT Wall-E remembers | GPS history, familiarity scores |
| **Return Home** | WHERE to go when tired | GPS navigation back to base |
| **Autonomy** | THE ORCHESTRATOR | Combines all above into behavior |

## 📡 WebUI Autonomy Page

### Displays Live
- Current State (IDLE/SCAN/TRACK/etc)
- Sonar distance (cm)
- Compass heading (degrees)
- Interest level (0-100)
- Emotion (name + intensity)
- Personality traits (sliders)
- GPS position
- Return Home status

### Controls
- **Enable/Disable** - Toggle autonomous mode
- **Set Home** - Mark current position as base

## 🔧 Troubleshooting

### Still Boot Looping?
Check serial output - it will stop at the failing module

### Can't Access WebUI?
- IP: `192.168.4.1` (AP mode always on)
- SSID: `WALL-E-xxxx`
- Password: Check `wifi_manager.cpp`

### Autonomy Does Nothing?
- Enable it first (button or WebUI)
- Check if joystick is active (overrides auto)
- Missing sensors = limited behavior

### How to Test Without Sensors?
- Autonomy works, just won't detect obstacles
- Use CYD for manual control
- WebUI shows "Not available" for missing sensors

## 🎯 Key Files Modified Today

### Main Changes
- `main/main.ino` - Graceful init, all engines integrated
- `main/autonomy_engine.cpp` - Fixed personality refs, removed duplicate struct
- `main/sonar_sensor.cpp` - Returns bool for graceful fail
- `main/return_home_engine.cpp` - Fixed struct initialization

### Documentation Added
- `BEHAVIORAL_BRAIN_COMPLETE_SUMMARY.md` ← Read this for full overview
- `GRACEFUL_DEGRADATION.md` ← How sensors fail safely
- `BOOT_LOOP_TROUBLESHOOTING.md` ← Watchdog debug guide
- `COMPILATION_FIX_2026-02-24.md` ← What was fixed

## 💡 Pro Tips

1. **Start Simple**: Boot without external sensors first
2. **Add Sensors**: One at a time (sonar → compass → GPS)
3. **Watch Serial**: See exactly what's happening
4. **Use WebUI**: Best way to monitor autonomy live
5. **Trust Joystick**: Manual control ALWAYS works

## 🎉 You Now Have

✅ Complete behavioral brain (14 modules)  
✅ Graceful sensor degradation  
✅ WebUI live telemetry  
✅ CYD integration  
✅ Production-ready code  

**Upload and let's see Wall-E wake up!** 🤖✨

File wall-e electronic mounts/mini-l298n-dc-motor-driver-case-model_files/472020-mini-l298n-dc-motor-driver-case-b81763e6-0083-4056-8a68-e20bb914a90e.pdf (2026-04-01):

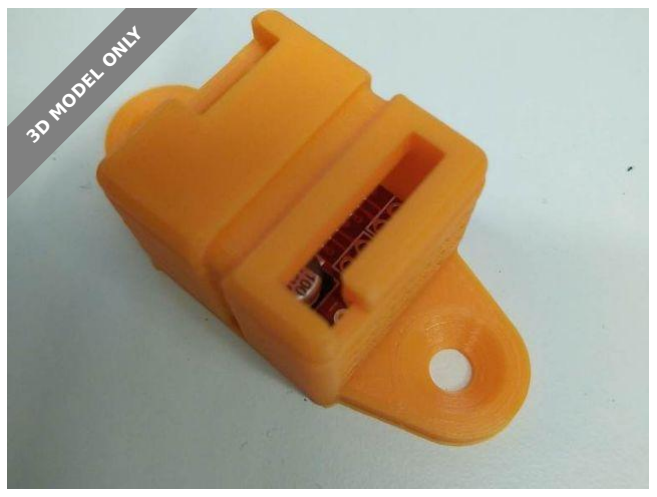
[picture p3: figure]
3D MODEL ONLY

## Summary

NOTICE !!! - This is for the L298N Mini! not the regular driver. The case is closed by a zip tie and includes mounting...

Hobby & Makers (https://printables.com/model?categoryId=48) > Electronics (https://printables.com/model?categoryId=52)

Tags: thingiverse | pwm | l298n | motordriver

NOTICE !!! - This is for the L298N Mini! not the regular driver.

The case is closed by a zip tie and includes mounting holes

the mini does not have the heatsinks, the screw connector or the enable input.

however it is smaller (and cheaper)

can be purchase from Banggod : https://www.banggood.com/3pcs-Dual-Channel-L298N-DC-Motor-Driver-Board-PWM-Speed-Dual-H-Bridge-Stepper-Module-p-1167074.html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 (https://www.banggood.com/3pcs-Dual-Channel-L298N-DC-Motor-Driver-Board-PWM-Speed-Dual-H-Bridge-Stepper-Module-p-1167074.html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)

Print Settings

Printer Brand:

Prusa

ShmilCat (https://printables.com/@ShmilCat_35205)

## Mini L298N DC

## Motor Driver Case

VIEW IN BROWSER (https://printables.com/model/472020-mini-l298n-dc-motor-driver-case)

updated 6. 5. 2023 | published 6. 5. 2023

## Model files

Printer:

i3 MK2.5

Rafts:

No

Supports:

No

Resolution:

0.2

Infill:

15%

Filament: Generic PLA PLA (http://www.amazon.com/s?url=search-alias&field-keywords=Generic+PLA+PLA) Orange

Notes:

Infill can be whatever you like.
I've put in some hexa-vent-holes that might challenge some printers.

Category: Electronics

Find source .stl files on Thingiverse.com (https://www.thingiverse.com/thing:3323457) motorcontrol_l298n_housing_11_cover.stl

motorcontrol_l298n_housing_11_base.stl

## License

This work is licensed under a
Creative Commons (4.0 International License)

Attribution (http://creativecommons.org/licenses/by/4.0/)

✖ | Sharing without ATTRIBUTION
✔ | Remix Culture allowed
✔ | Commercial Use
✔ | Free Cultural Works
✔ | Meets Open Definition

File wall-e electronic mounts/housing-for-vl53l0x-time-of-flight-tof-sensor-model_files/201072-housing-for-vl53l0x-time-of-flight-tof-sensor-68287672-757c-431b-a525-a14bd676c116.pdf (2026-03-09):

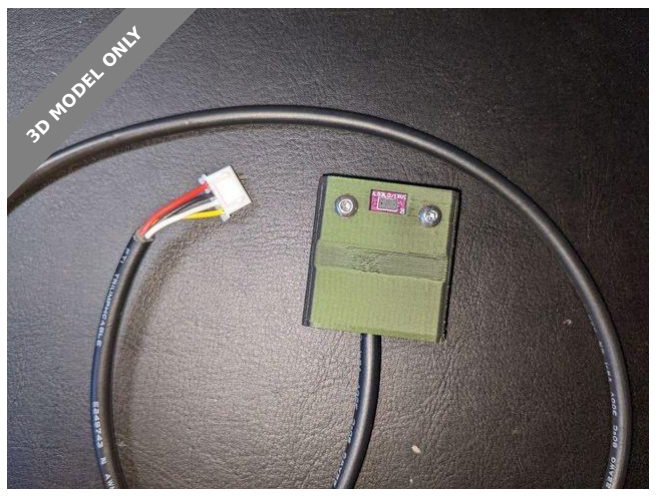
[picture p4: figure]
3D MODEL ONLY

## Summary

Description If you print in the orientation provided, you shouldn't need supports. Also included in the photos is my...

Hobby & Makers (https://www.printables.com/model?categoryId=48) > Tools (https://www.printables.com/model?categoryId=49)

Tags: case | sensor | housing | vl53l0x | timeofflight | tof

### Description

If you print in the orientation provided, you shouldn't need supports.

Also included in the photos is my Case for ElectroCookie Mini PCB Prototype Board. (https://www.thingiverse.com/thing:5320880)

This housing is designed to accommodate a VL53L0X Time-of-Flight (TOF) Sensor and a 4 wire cable (with 4 pin JST-XH connector). This sensor is used to accurately measure distances and appears to work up to about 1.5 meters.

The back of the Sensor Body (andoptional Sensor Back Clamp) have a 42mm diameter arc. I used this to attach to my stairs bannister. It shouldn't hinder you from using wherever, just use some double sided foam tape to attach. Additionally, the Sensor Front and (andoptional

D (https://www.printables.com/social/7295/about) DorffMeister (https://www.printables.com/social/7295/about)

## Housing for VL53L0X Time-of-Flight (TOF) sensor

VIEW IN BROWSER (https://www.printables.com/model/201072-housing-for-vl53l0x-time-of-flight-tof-sensor)

updated 9. 5. 2022 | published 9. 5. 2022

Sensor Back Clamp) have a recessed track in case you want to install using Zip Ties.

I didn't find it necessary to (super)glue the Sensor Body to the Sensor Front, but you can. I'm using Foam Tape and a Zip Tie to attach to my bannister, which seems good enough.

Use short M3 screws to attach the VL53L0X to the housing.

I used Bondic to help secure the i2c cable to the ToF sensor.

### What is the optional "Sensor Back Clamp" model for?

In case you are using a Zip Tie to attach to something like a stairs bannister, I added this optional second piece to keep the Zip Tie front digging into the back of the bannister.

### How I'm using it

I'm installing Stair Lights. I initially used a motion sensor at the top and bottom of the stairs to trigger the LEDs. Since I'm already using Home Assistant to control the automation, I decided to try using ESPHome running on an ESP8266 D1 Mini with a VL53L0X Time-of-Flight (TOF) sensor to detect motion.

### Want to use a VL53L0X ToF sensor as a Break Beam sensor with ESPHome?

Check out my code. (https://gist.github.com/kdorff/245ff51463b4845de6239deaaa21445e)

The benefits over a standard motion sensor

Motion sensors have a "cooldown" period. This would not, and should not need one.
I believe this is less sensitive to ghost triggers and can more easily be placed to avoid pets triggering it.

The downside compared to a motion sensor

Cannot easily be run from batteries and bulkier.

### Print Settings

Printer Brand:

Prusa

Printer:

•

•

•

## Model files

i3 MK3

Rafts:

No

Supports:

No

Resolution:

0.3mm

Infill:

20%

Filament: Prusament PLA, 1.75 Some awesome green

Category: Tool Holders & Boxes

Find source .stl files on Thingiverse.com (https://www.thingiverse.com/thing:5320907)

sensor_body.stl

sensor_back_clamp.stl

sensor_front.stl

## License

This work is licensed under a
Creative Commons (4.0 International License)

Attribution-NonCommercial (http://creativecommons.org/licenses/by-nc/4.0/)

✖ | Sharing without ATTRIBUTION
✔ | Remix Culture allowed
✖ | Commercial Use
✖ | Free Cultural Works
✖ | Meets Open Definition

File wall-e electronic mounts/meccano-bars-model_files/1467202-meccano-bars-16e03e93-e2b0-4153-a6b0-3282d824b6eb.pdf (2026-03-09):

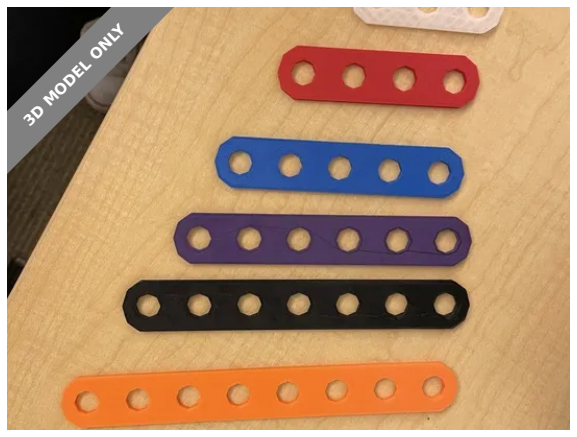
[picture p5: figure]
3D MODEL ONLY

## Summary

Meccano bars with 3-8 holes and a pin to connect them together

Learning (https://printables.com/model?categoryId=90) > Engineering (https://printables.com/model?categoryId=93)

Tags: | toy | assembly | construction | constructiontoys | meccano
meccanobar

A set of meccano bars with 3-8 holes and a pin to connect them. Perfect as a toy or for learning.

Used as part of an academic experiment, but can be used for a wide variety of purposes.

This work is distributed under a CC-BY-NC-SA license. No commercial use or derivatives are allowed. For commercial licensing please contact the designer.

KelleyArtAndDesign (https://printables.com/@KAAD_1431451)

## Meccano Bars

VIEW IN BROWSER (https://printables.com/model/1467202-meccano-bars)

updated 2. 11. 2025 | published 2. 11. 2025

## Model files

## License

This work is licensed under a
Creative Commons (4.0 International License) (http://creativecommons.org/licenses/by-nc-sa/4.0/)

bar-3.stl

bar-6.stl

bar-5.stl

bar-4.stl

bar-7.stl

bar-8.stl

bolt_final.stl

Attribution—Noncommercial—Share Alike (http://creativecommons.org/licenses/by-nc-sa/4.0/)

✖ | Sharing without ATTRIBUTION
✔ | Remix Culture allowed
✖ | Commercial Use
✖ | Free Cultural Works
✖ | Meets Open Definition

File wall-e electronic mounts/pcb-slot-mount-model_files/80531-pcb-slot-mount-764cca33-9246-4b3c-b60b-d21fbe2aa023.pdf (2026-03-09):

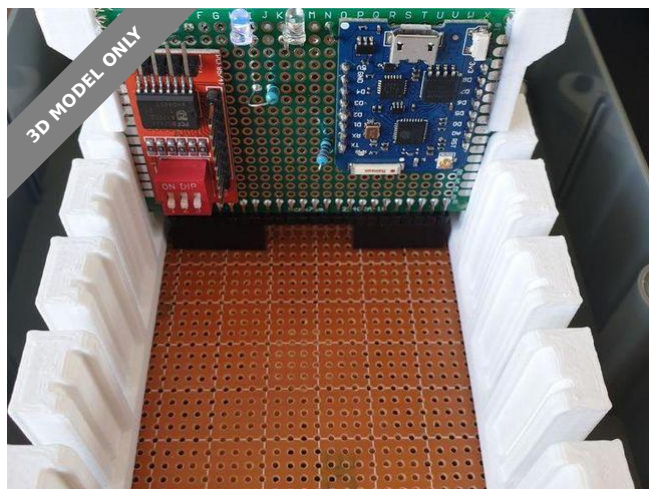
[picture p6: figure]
3D MODEL ONLY

# Model files

# Summary

The cards are 50mm x 70mm prototype PCB cards and the back PCB is

90mm x 150mm. The cards don't use screws. The PCB...

Hobby & Makers (https://www.printables.com/model?categoryId=48) | > | Electronics (https://www.printables.com/model?categoryId=52)
Tags: card | mount | slot | pcb | prototype

The cards are 50mm x 70mm prototype PCB cards and the back PCB is

90mm x 150mm.

The cards don't use screws. The PCB slots into the card cover and you use

a single male header pin on each end. You solder the pin onto the PCB and

let it sink into the cover and it will lock it in.

Category: Electronics

Aaron McNiven (https://www.printables.com/social/171279/about)

# PCB Slot Mount

VIEW IN BROWSER (https://www.printables.com/model/80531-pcb-slot-mount)

updated 12. 4. 2022 | published 16. 10. 2021

design.skp

Find source .stl files on Thingiverse.com (https://www.thingiverse.com/thing:3352613)

# License

This work is licensed under a

Creative Commons (4.0 International License)

Attribution (http://creativecommons.org/licenses/by/4.0/)

✖ | Sharing without ATTRIBUTION
✔ | Remix Culture allowed
✔ | Commercial Use
✔ | Free Cultural Works
✔ | Meets Open Definition

jaycar_box_pcb_mount_90x150.skp

pcb_cover.skp

card_guide.skp

pcb_cover.stl

card_guide.stl

jaycar_box_pcb_mount_90x150.stl

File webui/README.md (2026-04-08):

# Web UI — LROS (Lightweight Robot Operator Shell)

Static **HTML / CSS / JavaScript** assets for operating WALL-E from a **browser**: dashboard controls, status panels, and integration with the **base** HTTP API when the page is served from the robot’s network or opened against a known base URL.

---

## Purpose

- **Secondary operator surface** without the physical CYD master controller.
- **Rapid UI prototyping** before embedding strings in firmware.
- **Documentation-friendly** — no separate flash step for the assets themselves.

---

## Files

| File | Role |
|---|---|
| [index.html](index.html) | Primary LROS page |
| [index-standalone.html](index-standalone.html) | Offline or demo variant |
| [css/lros.css](css/lros.css) | Theme variables, layout |
| [js/lros.js](js/lros.js) | Fetch helpers, UI logic, operator strip, optional vision-event toasts, `apiAuthHeaders()` for optional base token |
| [js/lros-navigation.js](js/lros-navigation.js), [js/lros-maplibre-nav.js](js/lros-maplibre-nav.js), [js/lros-sequences.js](js/lros-sequences.js), [js/navMissionPanel.js](js/navMissionPanel.js), … | Navigation, sequences, map deck |

### Embedded build (base firmware PROGMEM)

To regenerate **`main_wall_E_base/main/web_page_lros.h`** from `webui/` sources (bundled CSS + JS):

```powershell
.\webui\build-embed.ps1
```

(On Windows PowerShell from repo root; see script for exact paths.)

---

## Dependencies

- Modern browser (**ES6+**).
- **Live control:** Reachable **base** IP (e.g. `192.168.4.1` on `WALL-E-Control` AP) and routes implemented in `main_wall_E_base/main/web_server.cpp`.
- **CORS:** If opening `index.html` from `file://`, browser security may block API calls — serve from the base or use a local static server.
- **Optional API token:** If the base has a token configured (`POST /api/security/token`), set **`localStorage.walle_api_token`** in the browser to match; protected fetches send **`X-Wall-E-Token`** (see `lros.js` / `lros-sequences.js` / `lros-navigation.js`).
- **Motion policy:** Operator strip shows **`motion_policy`** (`any` / `cyd_only` / `web_only`) from **`GET /api/motion/operator`**.

---

## Deployment (no separate firmware)

| Method | Steps |
|---|---|
| **SPIFFS / LittleFS** | Copy `webui/` into filesystem image and upload with base firmware if your build supports it. |
| **Direct open** | Open `index.html`; configure base URL in script if required. |
| **Embedded headers** | Some builds use `web_page_*.h` — minify assets and include as C strings (project-specific). |

---

## Node ID and MAC

- **Not applicable** — browser client only.
- **Security:** Treat the base HTTP API as **trusted LAN**; optional shared token on the base for mutating routes — see [main_wall_E_base/README.md](../main_wall_E_base/README.md).

---

## Communication responsibilities

| Path | Technology |
|---|---|
| **Browser → Base** | **HTTP** (REST or ad-hoc handlers) |
| **Master → Base** | **ESP-NOW** — parallel path; base **`motion_authority`** policy can restrict CYD vs HTTP drive |

**Chain:** LROS does **not** talk to the master CYD; both talk to the **base** (different transports). See [ARCHITECTURE.md](../ARCHITECTURE.md#2-webui--base--nodes-communication-chain).

---

## Extending the UI

1. Add markup in `index.html`.
2. Style with variables in `lros.css`.
3. Implement API calls in `lros.js`; document routes in [../main_wall_E_base/README.md](../main_wall_E_base/README.md) and [../CONTRIBUTING.md](../CONTRIBUTING.md).

---

## Known quirks and limitations

- **Auth** — Optional token on base for some POST/mutating routes; browser must send header when enabled.
- **Telemetry rate** — Browser polling interval should be reasonable to avoid overloading the base.

---

## See also

- [../CONTRIBUTING.md](../CONTRIBUTING.md)  
- [../README.md](../README.md)

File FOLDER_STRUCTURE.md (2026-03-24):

# Proposed Repository Layout

**Status:** Documentation only — **no repository moves have been performed**. Use this as a migration blueprint when the team agrees to reorganize.

---

## Current layout (summary)

| Area | Folders |
|---|---|
| Firmware | `wall_e_master_controller/`, `main_wall_E_base/`, `audio_esp/`, `vision_node/`, `vision_node_arduino/`, `dock_station/` |
| Shared code | `lib/` |
| Web | `webui/` |
| Docs / OTA | Root `README.md`, `ARCHITECTURE.md`, `OTA_README.md`, `ota_build_all.*` |
| Other | `paludarium_4relay/` (separate sketch), optional `wall-e electronic mounts/` (often untracked) |

**Pain points:** Duplicate protocol headers; two vision trees; mixed-purpose folders at repo root.

---

## Proposed layout

```
wall-e/
├── README.md
├── ARCHITECTURE.md
├── CONTRIBUTING.md
├── FOLDER_STRUCTURE.md
├── REPO_AUDIT.md
├── OTA_README.md
├── ota_config.ini
├── ota_build_all.ps1
├── ota_build_all.sh
│
├── docs/
│   ├── media/                 # Images, GIFs for README
│   └── diagrams/              # Optional exported SVGs
│
├── protocols/                 # Single source: packed structs + magic
│   ├── node_health.h
│   ├── dock.h
│   ├── vision.h
│   └── control_telemetry.h  # ControlPacket / TelemetryPacket
│
├── shared/                    # Renamed from lib/ (optional name)
│   ├── walle_emotion_pose/
│   ├── walle_audio_events/
│   └── walle_vision_events/
│
├── firmware/
│   ├── master_controller/     # wall_e_master_controller
│   ├── base/                  # main_wall_E_base
│   ├── audio/                 # audio_esp
│   ├── vision/                # Merge or pick canonical vision_node
│   ├── dock/                  # dock_station
│   └── legacy/                # vision_node_arduino if retained
│
├── webui/                     # Unchanged
├── tools/                     # Helper scripts (non-OTA)
└── third_party/
    └── paludarium_4relay/     # Optional move for clarity
```

---

## Reasoning

| Change | Benefit |
|---|---|
| `protocols/` | Eliminates drift; enables one CI job to compile-test includes. |
| `firmware/` | Clear “what flashes” vs docs and web assets. |
| `docs/media/` | Stable image URLs in README. |
| `third_party/` | Signals that not everything is core WALL-E firmware. |
| `shared/` (rename `lib/`) | Reduces confusion with Arduino “Library Manager” deps. |

---

## Migration plan (non-destructive)

### Phase 0 — No moves

- Add **`docs/media/`** and drop one hero image when ready.
- Document canonical **vision** path in root README (PlatformIO vs Arduino).

### Phase 1 — Include paths only

- Create **`protocols/`** with headers; add **`-I ../../protocols`** (or equivalent) to each `platformio.ini`.
- Keep old headers as **thin wrappers** `#include`ing the new file, or delete duplicates only after all builds pass.

### Phase 2 — Rename `lib/` → `shared/`

- `git mv lib shared`
- Update **`lib_extra_dirs`** and Arduino include paths in one PR.

### Phase 3 — `firmware/` renames

- `git mv wall_e_master_controller firmware/master_controller` (example)
- Update **every** `platformio.ini`, `src_dir`, and documentation link in the same PR.

### Phase 4 — Vision consolidation

- Deprecate one of `vision_node/` vs `vision_node_arduino/` or document **dual maintenance** with a checklist in `REPO_AUDIT.md`.

### Rollback

- Git history preserves paths; revert the merge commit if CI or users break.

---

## Minimal alternative

Add **`protocols/`** only — **no folder renames**. Highest ROI for correctness; lowest churn.

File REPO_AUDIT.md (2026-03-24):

# Repository Audit (Documentation & Structure)

**Scope:** Documentation gaps, naming consistency, protocol coverage, comment opportunities, and **future** refactors. **No source code was modified** to produce this report.

**Date:** Generated as part of documentation refinement.

---

## 1. Missing documentation

| Gap | Recommendation |
|-----|---|
| **Single “channel sync” guide** | Add `docs/RF_ESP_NOW.md`: set router/AP channel = base AP channel; verify with `WiFi.channel()`. |
| **`docs/media/`** | Root README references placeholders; create folder + one real image when available. |
| **LICENSE** | Root README notes absence; add SPDX file (MIT, Apache-2.0, etc.). |
| **CHANGELOG.md** | Optional; helps hardware builders track breaking protocol changes. |
| **Vision canonical path** | Explicitly state whether `vision_node/` (PlatformIO) or `vision_node_arduino/` is primary for new work. |
| **Audio protocol** | `audio_protocol.h` scattered — central summary table in ARCHITECTURE.md when stable. |
| **Master ↔ base packet version field** | Control/Telemetry have no explicit version byte — document upgrade strategy if structs evolve. |

---

## 2. Inconsistent naming

| Observation | Note |
|---|---|
| **`main_wall_E_base` vs “base”** | Folder name is historical; docs use “base” — acceptable if README states mapping once. |
| **`wall_e_audio` include path** | Referenced by `audio_esp` and others; not always a top-level folder in listing — verify on clone. |
| **`node_health_protocol.h` copies** | Same filename in `dock_station/`, `audio_esp/`, `wall_e_master_controller/`, etc. — risk of editing wrong file. |
| **`dock_protocol.h` copies** | Same — prefer grep across repo before editing. |
| **LROS vs webui** | “LROS” is the product name; folder is `webui/` — documented in README. |

---

## 3. Undocumented or under-documented protocols

| Protocol | Location | Gap |
|---|---|-----|
| **WalleNodeHealthPacket_t** | `node_health_protocol.h` | Timing guarantees not strict — document “best effort” and consumer timeouts. |
| **DockBeaconPacket_t** | `dock_protocol.h` | Field-by-field table in ARCHITECTURE (partially done). |
| **Audio ESP-NOW** | `audio_esp`, `audio_protocol.h` | End-to-end flow vs base not fully narrated in one place. |
| **Node health from dock** | `dock_espnow.cpp` | How dock populates health fields vs beacon — worth a short comment block in ARCHITECTURE. |
| **CYD ControlPacket** | `protocol.h` | Servo array length and behaviour modes — table in master README. |

---

## 4. Areas needing comments (source — suggestions only)

| Area | Suggestion |
|---|---|
| **ESP-NOW dispatch** | In `espnow_receiver.cpp`, a short comment block listing **magic → handler** improves onboarding. |
| **`build_src_filter` exclusions** | `walle_emotion_pose.cpp` excluded in base `platformio.ini` — one-line comment why duplicate symbol is avoided. |
| **Dock `ENABLE_WIFI 0`** | When Wi-Fi off, `ir_align_hint` not sent over air — comment near beacon fill. |
| **IR alignment vs beam** | Already separated in code; add file-level note in `dock_sensors.cpp` if still confusing. |

*Do not edit code unless the team approves; this is a checklist.*

---
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

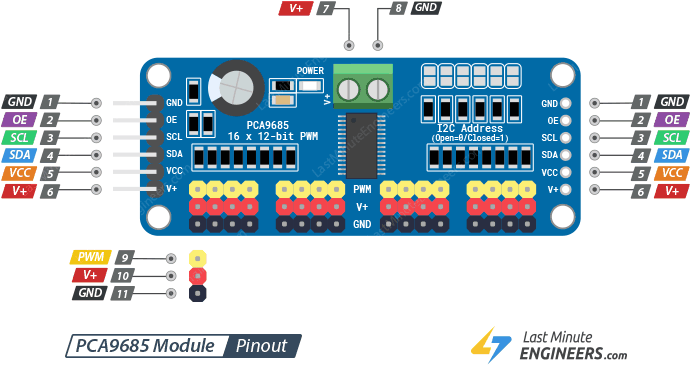
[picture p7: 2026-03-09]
wall-e electronic mounts/PCA9685-Module-Pinout.png

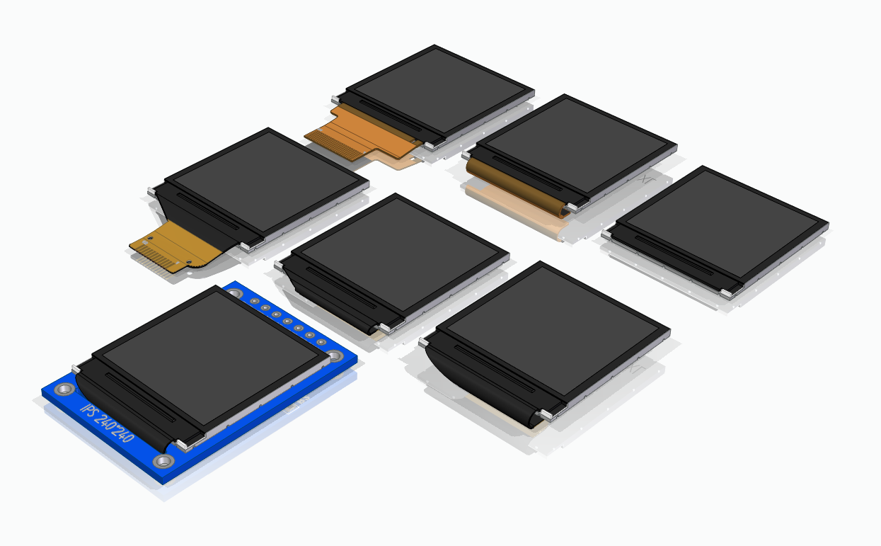
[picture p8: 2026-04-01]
wall-e electronic mounts/1-3-tft-ips-module-st7789-1.snapshot.17/Assortment2.PNG

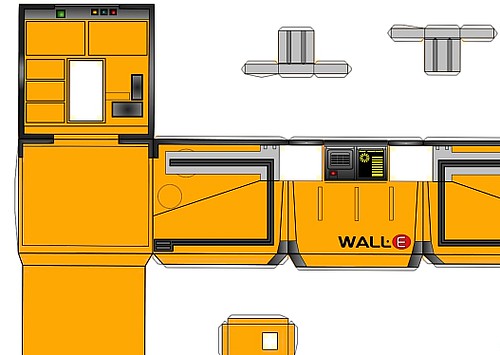
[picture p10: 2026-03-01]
2381302478_5b9a3a2740_e.jpg

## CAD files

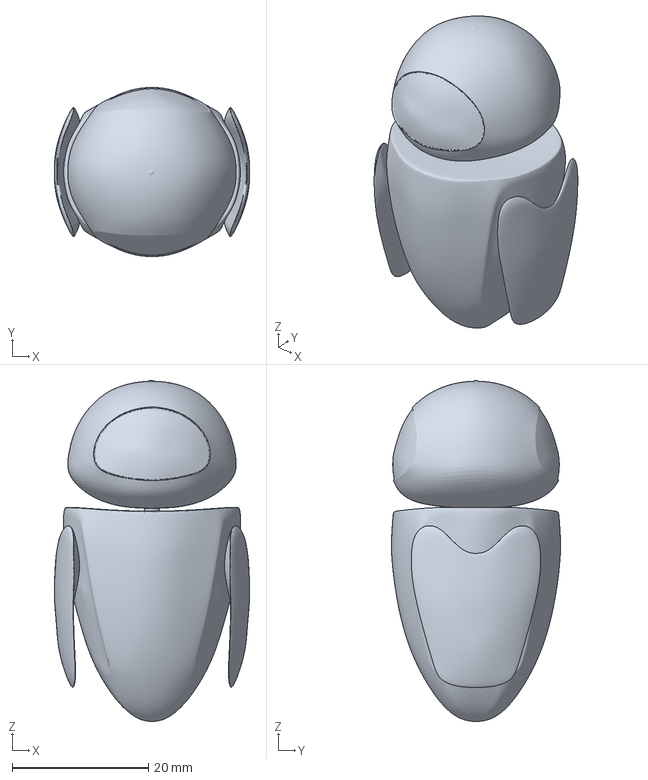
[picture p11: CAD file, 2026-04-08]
eve/Meshy_AI_Blue-Eyed Droid_1775645156_generate.3mf
28.7 x 24.8 x 50.0 mm

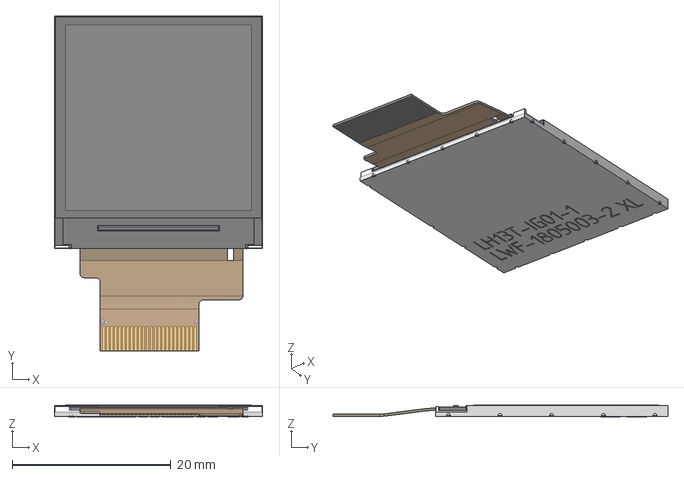
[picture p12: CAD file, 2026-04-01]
wall-e electronic mounts/1-3-tft-ips-module-st7789-1.snapshot.17/1.3 TFT IPS - 24 Pin - Socket Flat.stp
26.2 x 42.2 x 1.46 mm

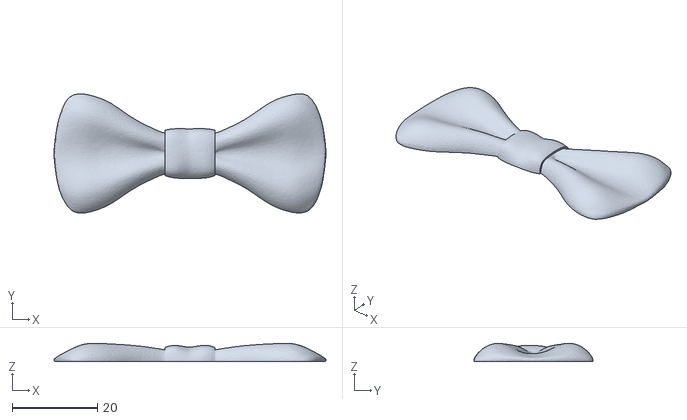
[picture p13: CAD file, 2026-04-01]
wall-e electronic mounts/bow tie REMIX FLAT.stl
63.9 x 28.0 x 4.33

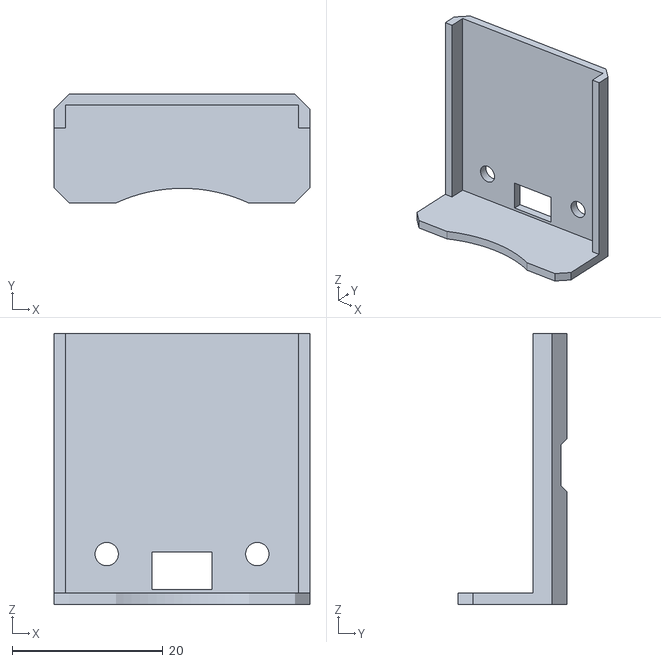
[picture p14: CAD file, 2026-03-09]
wall-e electronic mounts/housing-for-vl53l0x-time-of-flight-tof-sensor-model_files/sensor_front.stl
34.0 x 14.5 x 36.0

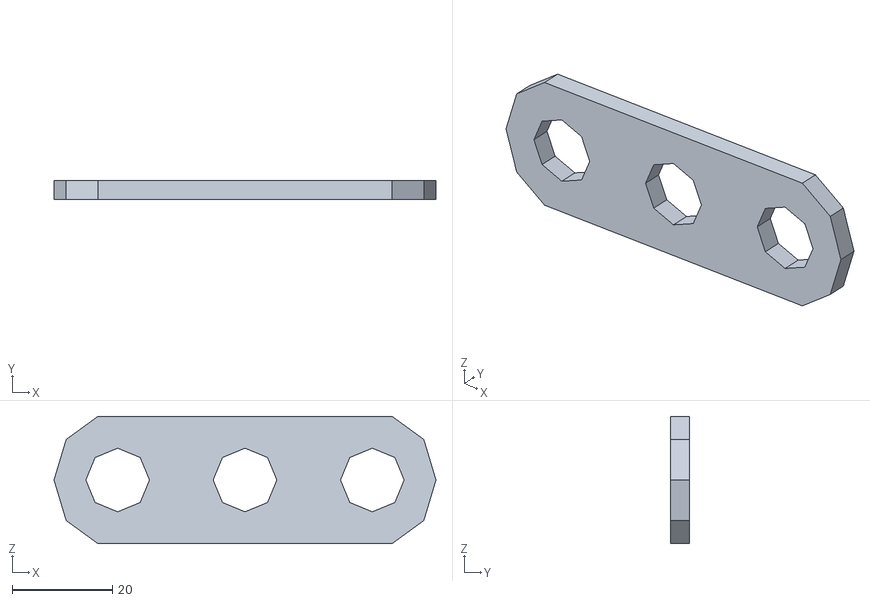
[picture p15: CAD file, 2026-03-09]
wall-e electronic mounts/meccano-bars-model_files/bar-3.stl
76.2 x 3.81 x 25.4

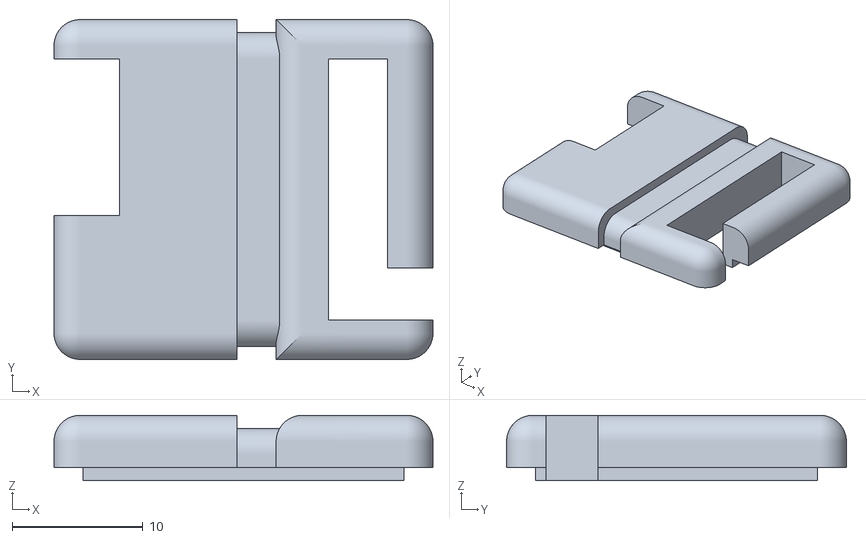
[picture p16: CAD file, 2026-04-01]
wall-e electronic mounts/mini-l298n-dc-motor-driver-case-model_files/MotorControl_L298N_Housing_1.1_Cover.stl
29.0 x 26.0 x 5.00

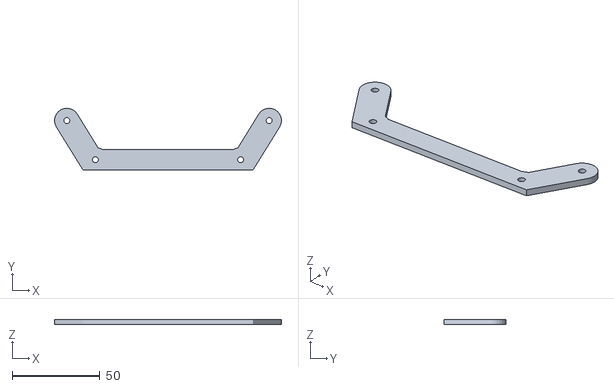
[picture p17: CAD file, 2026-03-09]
wall-e electronic mounts/pcb-slot-mount-model_files/jaycar_box_pcb_mount_90x150.stl
129.0 x 35.0 x 3.00

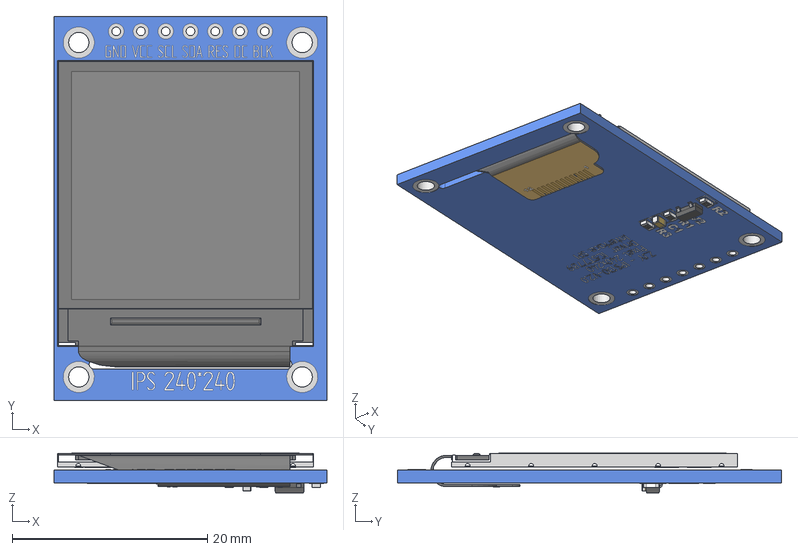
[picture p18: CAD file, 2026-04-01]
wall-e electronic mounts/1-3-tft-ips-module-st7789-1.snapshot.17/1.3 TFT IPS - Module.stp
27.9 x 39.4 x 4.06 mm
1.3 TFT IPS - Board
1.3 TFT IPS - Flush Reverse Mount
0603 Resistor x 3
0603 Capacitor
SOT-23

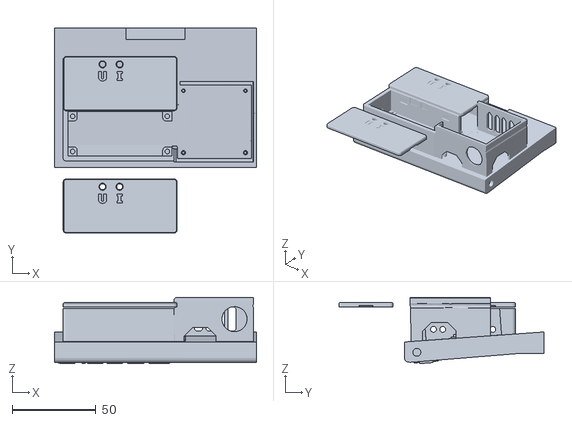
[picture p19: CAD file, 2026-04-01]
wall-e electronic mounts/body-front-door - with covers_260320_213831.stl
120.5 x 122.6 x 39.6

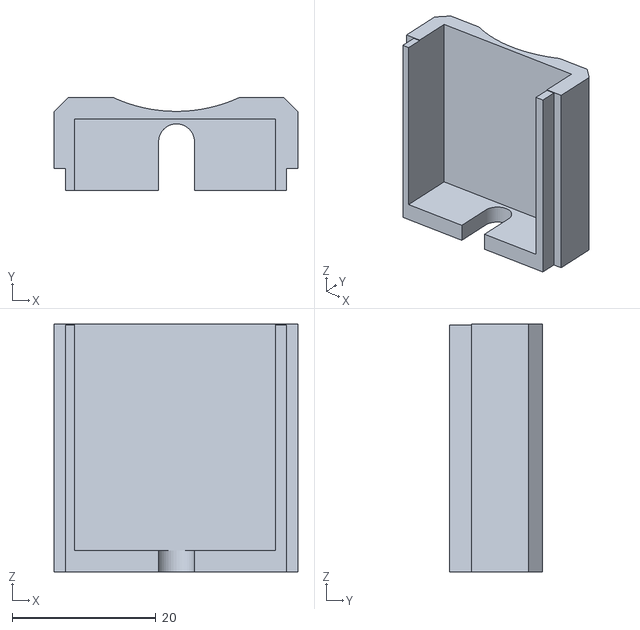
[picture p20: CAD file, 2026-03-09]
wall-e electronic mounts/housing-for-vl53l0x-time-of-flight-tof-sensor-model_files/sensor_body.stl
34.0 x 13.0 x 34.5

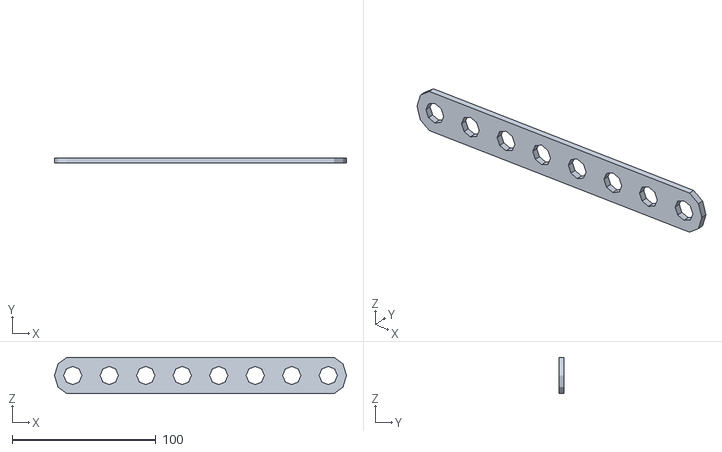
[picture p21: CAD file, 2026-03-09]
wall-e electronic mounts/meccano-bars-model_files/bar-8.stl
203.2 x 3.81 x 25.4

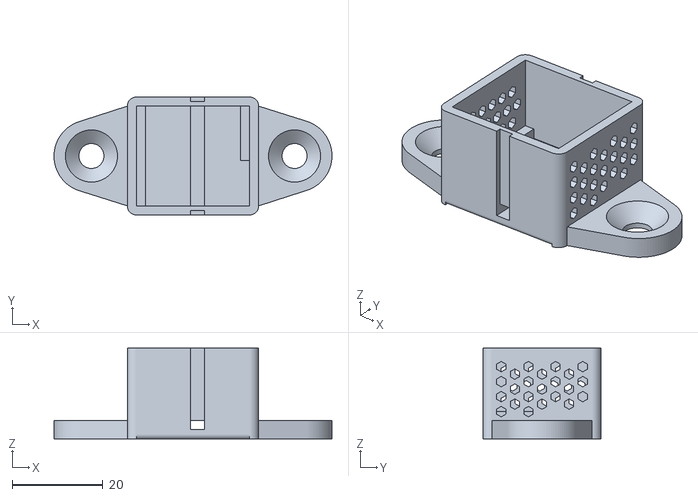
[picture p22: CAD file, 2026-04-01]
wall-e electronic mounts/mini-l298n-dc-motor-driver-case-model_files/MotorControl_L298N_Housing_1.1_Base.stl
61.4 x 26.0 x 20.0

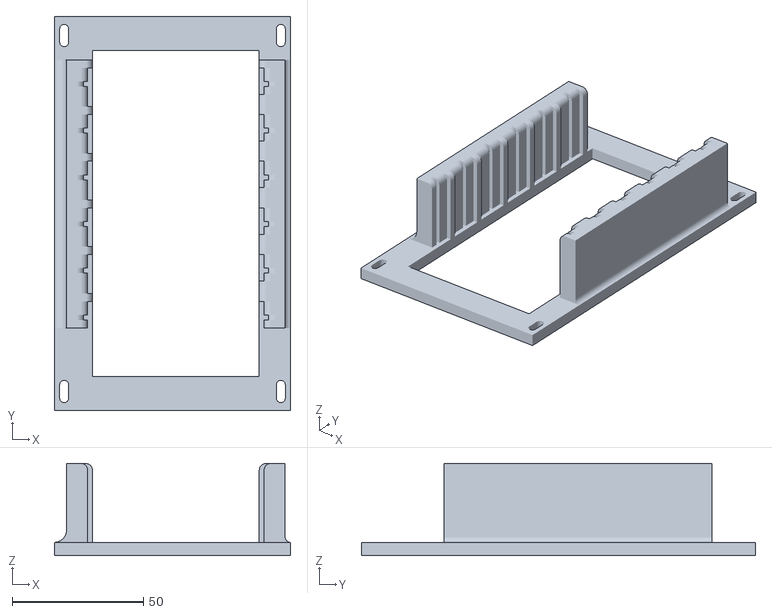
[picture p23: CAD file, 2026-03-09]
wall-e electronic mounts/pcb-slot-mount-model_files/card_guide.stl
90.0 x 150.0 x 35.0

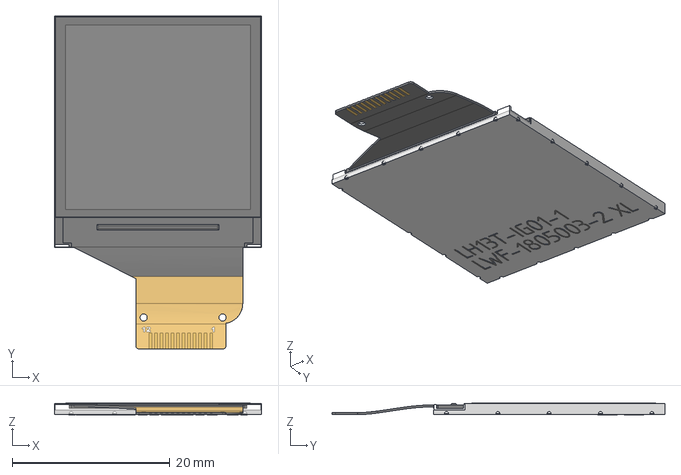
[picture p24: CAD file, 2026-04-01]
wall-e electronic mounts/1-3-tft-ips-module-st7789-1.snapshot.17/1.3 TFT IPS - Flat Mount.stp
26.2 x 42.2 x 1.46 mm

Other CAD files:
wall-e electronic mounts/housing-for-vl53l0x-time-of-flight-tof-sensor-model_files/sensor_back_clamp.stl
wall-e electronic mounts/meccano-bars-model_files/bar-7.stl
wall-e electronic mounts/pcb-slot-mount-model_files/pcb_cover.stl
wall-e electronic mounts/xl4015 CC CV Buck Converter Case.3mf
wall-e electronic mounts/1-3-tft-ips-module-st7789-1.snapshot.17/1.3 TFT IPS - 24 Pin - Socket Revers Mount.stp
wall-e electronic mounts/1-3-tft-ips-module-st7789-1.snapshot.17/1.3 TFT IPS - Flush Mount.stp
wall-e electronic mounts/1-3-tft-ips-module-st7789-1.snapshot.17/1.3 TFT IPS - Flush Reverse Mount.stp
wall-e electronic mounts/1-3-tft-ips-module-st7789-1.snapshot.17/1.3 TFT IPS - No Cable.stp
wall-e electronic mounts/1.3 TFT IPS - Module.stp.stl
wall-e electronic mounts/815 Servo Driver 16 Channel.stl
wall-e electronic mounts/BracketLock_ESP32_36pin.stl
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

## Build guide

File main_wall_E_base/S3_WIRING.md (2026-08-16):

# WALL-E Base Brain — ESP32-S3 Wiring

Production target: **ESP32-S3 Dev Module / ESP32-S3-DevKitC-1 class board**.

The authoritative firmware definitions live in `main/base_board_pins.h`.

## Architecture

- The ESP32-S3 is the WALL-E Base Brain.
- Wi-Fi and ESP-NOW run directly on the S3.
- CYD, audio, vision and dock remain ESP-NOW nodes.
- No ESP32-P4 is required.
- No ESP32-C6 radio gateway is required.
- The old local ST7789 Base display is not used; CYD/LROS remain the operator interfaces.

## GPIO map

| WALL-E function | ESP32-S3 GPIO | Notes |
|---|---:|---|
| Left motor IN1 | 4 | L298N |
| Left motor IN2 | 5 | L298N |
| Left motor ENA | 6 | PWM |
| Right motor IN3 | 7 | L298N |
| Right motor IN4 | 8 | L298N |
| Right motor ENB | 9 | PWM |
| Battery monitor ADC | 1 | ADC1 |
| Current monitor ADC | 2 | ADC1 |
| LDR ADC | 10 | ADC1 |
| Flashlight MOSFET | 11 | Digital output |
| Eye laser | 12 | PWM output |
| Sonar trigger | 13 | Output |
| Sonar echo | 14 | Input — level shift if sensor echo is 5 V |
| Dock IR left | 15 | ~38 kHz PWM |
| Dock IR right | 16 | ~38 kHz PWM |
| I2C SDA | 17 | PCA9685 + MPU6050 + compass + VL53L1X |
| I2C SCL | 18 | Shared I2C bus |
| GPS RX | 21 | Connect to GPS TX; GPS is receive-only |
| Obstacle front-left | 38 | Input |
| Obstacle front-right | 39 | Input |
| Obstacle rear-left | 40 | Input |
| Obstacle rear-right | 41 | Input |

## Pins deliberately left alone

- GPIO0, GPIO3, GPIO45 and GPIO46: boot/strapping pins.
- GPIO19 and GPIO20: kept free for native USB / USB-JTAG.
- GPIO26 through GPIO37: not used because these may be occupied by flash/PSRAM depending on the S3 module.
- GPIO43 and GPIO44: kept free for UART0 / serial diagnostics.
- GPIO47 and GPIO48: left spare.

## PCA9685 servo channels

| Channel | Servo |
|---:|---|
| 0 | Head pan |
| 1 | Upper neck / head tilt |
| 2 | Lower neck |
| 3 | Right eye |
| 4 | Left eye |
| 5 | Left arm |
| 6 | Right arm |
| 7 | Left eyebrow |
| 8 | Right eyebrow |
| 9–15 | Spare |

## First bench test order

1. Flash the S3 with motor power disconnected.
2. Confirm Serial shows `[WALL-E/S3] Starting Base Brain...` and native ESP-NOW starts.
3. Verify the I2C bus and PCA9685 before connecting servo power.
4. Verify battery/current ADC readings against a multimeter.
5. Verify the CYD link and E-stop.
6. Test each servo individually.
7. Connect the L298N logic lines with WALL-E lifted so the tracks cannot drive him off the bench.
8. Add sonar, GPS, obstacle sensors and dock IR one subsystem at a time.

## Safety

ESP32-S3 GPIO is 3.3 V logic. Do not connect a 5 V ultrasonic echo or other 5 V logic output directly to an S3 GPIO. Use a divider or level shifter where needed.

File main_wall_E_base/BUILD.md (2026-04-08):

# WALL-E Base Brain

**Flash this project** for the main robot controller (base brain).  
The WebUI shows **Base v1.2** in the top bar when you’re on the correct page.

## Build & upload
```bash
cd main_wall_E_base
pio run -t upload
```

For OTA, set `upload_port` in `platformio.ini` to your device IP (e.g. `192.168.4.1`), then:
```bash
pio run -t upload
```

## WebUI
Connect to WALL-E AP → `http://192.168.4.1`  
If Settings look wrong, hard-refresh (Ctrl+F5) or add `?v=1` to the URL to bypass cache.

Full route list and operator features (motion policy, sequences, optional API token): **[README.md](README.md)**.  
To rebuild embedded PROGMEM HTML from `../webui/`: **`../webui/build-embed.ps1`**.

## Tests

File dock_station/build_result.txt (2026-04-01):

Processing dock_esp32 (platform: espressif32; framework: arduino; board: esp32-s3-devkitc-1)
--------------------------------------------------------------------------------
Verbose mode can be enabled via `-v, --verbose` option
CONFIGURATION: https://docs.platformio.org/page/boards/espressif32/esp32-s3-devkitc-1.html
PLATFORM: Espressif 32 (6.12.0) > Espressif ESP32-S3-DevKitC-1-N8 (8 MB QD, No PSRAM)
HARDWARE: ESP32S3 240MHz, 320KB RAM, 8MB Flash
DEBUG: Current (esp-builtin) On-board (esp-builtin) External (cmsis-dap, esp-bridge, esp-prog, iot-bus-jtag, jlink, minimodule, olimex-arm-usb-ocd, olimex-arm-usb-ocd-h, olimex-arm-usb-tiny-h, olimex-jtag-tiny, tumpa)
PACKAGES: 
 - framework-arduinoespressif32 @ 3.20017.241212+sha.dcc1105b 
 - tool-esptoolpy @ 2.40900.250804 (4.9.0) 
 - toolchain-riscv32-esp @ 8.4.0+2021r2-patch5 
 - toolchain-xtensa-esp32s3 @ 8.4.0+2021r2-patch5
Converting dock_station.ino
LDF: Library Dependency Finder -> https://bit.ly/configure-pio-ldf
LDF Modes: Finder ~ chain, Compatibility ~ soft
Found 37 compatible libraries
Scanning dependencies...
Dependency Graph
|-- FastLED @ 3.10.3
|-- Adafruit SSD1306 @ 2.5.16
|-- Adafruit GFX Library @ 1.12.5
|-- WiFi @ 2.0.0
|-- Wire @ 2.0.0
|-- Preferences @ 2.0.0
|-- ArduinoOTA @ 2.0.0
|-- Adafruit BusIO @ 1.17.4
|-- SPI @ 2.0.0
Building in release mode
Compiling .pio\build\dock_esp32\src\dock_station.ino.cpp.o
Compiling .pio\build\dock_esp32\lib91b\FastLED\fl\fft_impl.cpp.o
Compiling .pio\build\dock_esp32\lib91b\FastLED\fl\file_system.cpp.o
Compiling .pio\build\dock_esp32\lib91b\FastLED\fl\json.cpp.o
Compiling .pio\build\dock_esp32\lib91b\FastLED\fl\raster_sparse.cpp.o
Compiling .pio\build\dock_esp32\lib91b\FastLED\fl\rgbw.cpp.o
Compiling .pio\build\dock_esp32\lib91b\FastLED\fl\screenmap.cpp.o
Compiling .pio\build\dock_esp32\lib91b\FastLED\fl\splat.cpp.o
Compiling .pio\build\dock_esp32\lib91b\FastLED\fl\str.cpp.o
Compiling .pio\build\dock_esp32\lib91b\FastLED\fl\str_ui.cpp.o
Compiling .pio\build\dock_esp32\lib91b\FastLED\fl\strstream.cpp.o
Compiling .pio\build\dock_esp32\lib91b\FastLED\fl\task.cpp.o
Compiling .pio\build\dock_esp32\lib91b\FastLED\fl\tile2x2.cpp.o
Compiling .pio\build\dock_esp32\lib91b\FastLED\fl\time.cpp.o
Compiling .pio\build\dock_esp32\lib91b\FastLED\fl\time_alpha.cpp.o
Compiling .pio\build\dock_esp32\lib91b\FastLED\fl\transform.cpp.o
Compiling .pio\build\dock_esp32\lib91b\FastLED\fl\type_traits.cpp.o
Compiling .pio\build\dock_esp32\lib91b\FastLED\fl\ui.cpp.o
Compiling .pio\build\dock_esp32\lib91b\FastLED\fl\upscale.cpp.o
Compiling .pio\build\dock_esp32\lib91b\FastLED\fl\wave_simulation.cpp.o
Compiling .pio\build\dock_esp32\lib91b\FastLED\fl\wave_simulation_real.cpp.o
Compiling .pio\build\dock_esp32\lib91b\FastLED\fl\xmap.cpp.o
Compiling .pio\build\dock_esp32\lib91b\FastLED\fl\xymap.cpp.o
Compiling .pio\build\dock_esp32\lib91b\FastLED\fl\xypath.cpp.o
Compiling .pio\build\dock_esp32\lib91b\FastLED\fl\xypath_impls.cpp.o
Compiling .pio\build\dock_esp32\lib91b\FastLED\fl\xypath_renderer.cpp.o
Compiling .pio\build\dock_esp32\lib91b\FastLED\fx\2d\blend.cpp.o
Compiling .pio\build\dock_esp32\lib91b\FastLED\fx\2d\luminova.cpp.o
Compiling .pio\build\dock_esp32\lib91b\FastLED\fx\2d\noisepalette.cpp.o
Compiling .pio\build\dock_esp32\lib91b\FastLED\fx\2d\scale_up.cpp.o
Compiling .pio\build\dock_esp32\lib91b\FastLED\fx\2d\wave.cpp.o
Compiling .pio\build\dock_esp32\lib91b\FastLED\fx\detail\fx_layer.cpp.o
Compiling .pio\build\dock_esp32\lib91b\FastLED\fx\frame.cpp.o
Compiling .pio\build\dock_esp32\lib91b\FastLED\fx\fx_engine.cpp.o
Compiling .pio\build\dock_esp32\lib91b\FastLED\fx\time.cpp.o
Compiling .pio\build\dock_esp32\lib91b\FastLED\fx\video.cpp.o
Compiling .pio\build\dock_esp32\lib91b\FastLED\fx\video\frame_interpolator.cpp.o
Compiling .pio\build\dock_esp32\lib91b\FastLED\fx\video\frame_tracker.cpp.o
Compiling .pio\build\dock_esp32\lib91b\FastLED\fx\video\pixel_stream.cpp.o
Compiling .pio\build\dock_esp32\lib91b\FastLED\fx\video\video_impl.cpp.o
Compiling .pio\build\dock_esp32\lib91b\FastLED\hsv2rgb.cpp.o
Compiling .pio\build\dock_esp32\lib91b\FastLED\lib8tion.cpp.o
Compiling .pio\build\dock_esp32\lib91b\FastLED\noise.cpp.o
Compiling .pio\build\dock_esp32\lib91b\FastLED\platforms.cpp.o
Compiling .pio\build\dock_esp32\lib91b\FastLED\platforms\adafruit\clockless.cpp.o
Compiling .pio\build\dock_esp32\lib91b\FastLED\platforms\arm\k20\clockless_objectfled.cpp.o
Compiling .pio\build\dock_esp32\lib91b\FastLED\platforms\arm\mgm240\fastpin_arm_mgm240.cpp.o
Compiling .pio\build\dock_esp32\lib91b\FastLED\platforms\compile_test.cpp.o
Compiling .pio\build\dock_esp32\lib91b\FastLED\platforms\esp\32\audio\audio.cpp.o
Compiling .pio\build\dock_esp32\lib91b\FastLED\platforms\esp\32\audio\sound_util.cpp.o
Compiling .pio\build\dock_esp32\lib91b\FastLED\platforms\esp\32\clockless_i2s_esp32s3.cpp.o
Compiling .pio\build\dock_esp32\lib91b\FastLED\platforms\esp\32\i2s\i2s_esp32dev.cpp.o
Compiling .pio\build\dock_esp32\lib91b\FastLED\platforms\esp\32\rmt_4\idf4_rmt.cpp.o
Compiling .pio\build\dock_esp32\lib91b\FastLED\platforms\esp\32\rmt_4\idf4_rmt_impl.cpp.o
Compiling .pio\build\dock_esp32\lib91b\FastLED\platforms\esp\32\rmt_5\idf5_rmt.cpp.o
platformio.exe 
: .pio/libdeps/d
ock_esp32/FastLE
D/src/platforms/
esp/32/clockless
_i2s_esp32s3.cpp
:10:2: warning: 
#warning "esp_me
mory_utils.h is 
not available, 
are you on 
esp-idf 4? The 
parallel 
clockless i2s 
driver will not 
be available" 
[-Wcpp]
At line:1 
char:63
+ ... 
lyContinue; & "C
:\Users\tjpro\.p
latformio\penv\S
cripts\platformi
o.exe ...
+               
  ~~~~~~~~~~~~~~
~~~~~~~~~~~~~~~~
~~~~~~~~~~~~~~~~
~~~~~~~~~~~
    + CategoryI 
   nfo          
    : NotSpec   
 ified: (.pi    
o/libdeps/d    
o...ilable"     
[-Wcpp]:St    
ring) [], R    
emoteExcept    
ion
    + FullyQual 
   ifiedErrorI  
  d : NativeC   
 ommandError
 
 #warning "esp_m
emory_utils.h 
is not 
available, are 
you on esp-idf 
4? The parallel 
clockless i2s 
driver will not 
be available"
  ^~~~~~~
Compiling .pio\build\dock_esp32\lib91b\FastLED\platforms\esp\32\rmt_5\strip_rmt.cpp.o
Compiling .pio\build\dock_esp32\lib91b\FastLED\platforms\esp\32\spi_ws2812\strip_spi.cpp.o
Compiling .pio\build\dock_esp32\lib91b\FastLED\platforms\stub\Arduino.cpp.o
Compiling .pio\build\dock_esp32\lib91b\FastLED\platforms\stub\led_sysdefs_stub.cpp.o
Compiling .pio\build\dock_esp32\lib91b\FastLED\platforms\stub\time_stub.cpp.o
Compiling .pio\build\dock_esp32\lib91b\FastLED\platforms\wasm\active_strip_data.cpp.o
Compiling .pio\build\dock_esp32\lib91b\FastLED\platforms\wasm\engine_listener.cpp.o
Compiling .pio\build\dock_esp32\lib91b\FastLED\platforms\wasm\entry_point.cpp.o
Compiling .pio\build\dock_esp32\lib91b\FastLED\platforms\wasm\fastspi_wasm.cpp.o
Compiling .pio\build\dock_esp32\lib91b\FastLED\platforms\wasm\fs_wasm.cpp.o
Compiling .pio\build\dock_esp32\lib91b\FastLED\platforms\wasm\js.cpp.o
Compiling .pio\build\dock_esp32\lib91b\FastLED\platforms\wasm\js_bindings.cpp.o
Compiling .pio\build\dock_esp32\lib91b\FastLED\platforms\wasm\js_fetch.cpp.o
Compiling .pio\build\dock_esp32\lib91b\FastLED\platforms\wasm\timer.cpp.o
Compiling .pio\build\dock_esp32\lib91b\FastLED\platforms\wasm\ui.cpp.o
Compiling .pio\build\dock_esp32\lib91b\FastLED\power_mgt.cpp.o
Compiling .pio\build\dock_esp32\lib91b\FastLED\sensors\button.cpp.o
Compiling .pio\build\dock_esp32\lib91b\FastLED\sensors\digital_pin.cpp.o
Compiling .pio\build\dock_esp32\lib91b\FastLED\sensors\pir.cpp.o
Compiling .pio\build\dock_esp32\lib91b\FastLED\simplex.cpp.o
Compiling .pio\build\dock_esp32\lib91b\FastLED\third_party\cq_kernel\cq_kernel.cpp.o
Compiling .pio\build\dock_esp32\lib91b\FastLED\third_party\cq_kernel\kiss_fft.cpp.o
Compiling .pio\build\dock_esp32\lib91b\FastLED\third_party\cq_kernel\kiss_fftr.cpp.o
Compiling .pio\build\dock_esp32\lib91b\FastLED\third_party\espressif\led_strip\src\led_strip_api.c.o
Compiling .pio\build\dock_esp32\lib91b\FastLED\third_party\espressif\led_strip\src\led_strip_rmt_dev.c.o
Compiling .pio\build\dock_esp32\lib91b\FastLED\third_party\espressif\led_strip\src\led_strip_rmt_encoder.c.o
Compiling .pio\build\dock_esp32\lib91b\FastLED\third_party\espressif\led_strip\src\led_strip_spi_dev.c.o
Compiling .pio\build\dock_esp32\lib91b\FastLED\third_party\object_fled\src\OjectFLED.cpp.o
Compiling .pio\build\dock_esp32\lib91b\FastLED\transpose8x1_noinline.cpp.o
Compiling .pio\build\dock_esp32\lib91b\FastLED\wiring.cpp.o
Compiling .pio\build\dock_esp32\lib9c6\Wire\Wire.cpp.o
Compiling .pio\build\dock_esp32\lib88c\Adafruit BusIO\Adafruit_BusIO_Register.cpp.o
Compiling .pio\build\dock_esp32\lib88c\Adafruit BusIO\Adafruit_GenericDevice.cpp.o
Compiling .pio\build\dock_esp32\lib88c\Adafruit BusIO\Adafruit_I2CDevice.cpp.o
Compiling .pio\build\dock_esp32\lib88c\Adafruit BusIO\Adafruit_SPIDevice.cpp.o
Compiling .pio\build\dock_esp32\libc69\Adafruit GFX Library\Adafruit_GFX.cpp.o
Compiling .pio\build\dock_esp32\libc69\Adafruit GFX Library\Adafruit_GrayOLED.cpp.o
Compiling .pio\build\dock_esp32\libc69\Adafruit GFX Library\Adafruit_SPITFT.cpp.o
Compiling .pio\build\dock_esp32\libc69\Adafruit GFX Library\glcdfont.c.o
Compiling .pio\build\dock_esp32\lib3e8\Adafruit SSD1306\Adafruit_SSD1306.cpp.o
Compiling .pio\build\dock_esp32\lib203\WiFi\WiFi.cpp.o
Compiling .pio\build\dock_esp32\lib203\WiFi\WiFiAP.cpp.o
Archiving .pio\build\dock_esp32\lib91b\libFastLED.a
Archiving .pio\build\dock_esp32\lib9c6\libWire.a
Compiling .pio\build\dock_esp32\lib203\WiFi\WiFiClient.cpp.o
Compiling .pio\build\dock_esp32\lib203\WiFi\WiFiGeneric.cpp.o
Compiling .pio\build\dock_esp32\lib203\WiFi\WiFiMulti.cpp.o
Compiling .pio\build\dock_esp32\lib203\WiFi\WiFiSTA.cpp.o
Archiving .pio\build\dock_esp32\lib88c\libAdafruit BusIO.a
Compiling .pio\build\dock_esp32\lib203\WiFi\WiFiScan.cpp.o
Compiling .pio\build\dock_esp32\lib203\WiFi\WiFiServer.cpp.o
Compiling .pio\build\dock_esp32\lib203\WiFi\WiFiUdp.cpp.o
Compiling .pio\build\dock_esp32\lib5ac\Preferences\Preferences.cpp.o
Archiving .pio\build\dock_esp32\libc69\libAdafruit GFX Library.a
Compiling .pio\build\dock_esp32\libacb\Update\HttpsOTAUpdate.cpp.o
Archiving .pio\build\dock_esp32\lib3e8\libAdafruit SSD1306.a
Compiling .pio\build\dock_esp32\libacb\Update\Updater.cpp.o
Compiling .pio\build\dock_esp32\libd5b\ESPmDNS\ESPmDNS.cpp.o
Compiling .pio\build\dock_esp32\lib3ed\ArduinoOTA\ArduinoOTA.cpp.o
Compiling .pio\build\dock_esp32\FrameworkArduino\Esp.cpp.o
Compiling .pio\build\dock_esp32\FrameworkArduino\FirmwareMSC.cpp.o
Compiling .pio\build\dock_esp32\FrameworkArduino\FunctionalInterrupt.cpp.o
Compiling .pio\build\dock_esp32\FrameworkArduino\HWCDC.cpp.o
Compiling .pio\build\dock_esp32\FrameworkArduino\HardwareSerial.cpp.o
Compiling .pio\build\dock_esp32\FrameworkArduino\IPAddress.cpp.o
Compiling .pio\build\dock_esp32\FrameworkArduino\IPv6Address.cpp.o
Archiving .pio\build\dock_esp32\lib203\libWiFi.a
Compiling .pio\build\dock_esp32\FrameworkArduino\MD5Builder.cpp.o
Archiving .pio\build\dock_esp32\lib5ac\libPreferences.a
Compiling .pio\build\dock_esp32\FrameworkArduino\Print.cpp.o
Archiving .pio\build\dock_esp32\libacb\libUpdate.a
Compiling .pio\build\dock_esp32\FrameworkArduino\Stream.cpp.o
Compiling .pio\build\dock_esp32\FrameworkArduino\StreamString.cpp.o
Archiving .pio\build\dock_esp32\libd5b\libESPmDNS.a
Compiling .pio\build\dock_esp32\FrameworkArduino\Tone.cpp.o
Compiling .pio\build\dock_esp32\FrameworkArduino\USB.cpp.o
Archiving .pio\build\dock_esp32\lib3ed\libArduinoOTA.a
Compiling .pio\build\dock_esp32\FrameworkArduino\USBCDC.cpp.o
Compiling .pio\build\dock_esp32\FrameworkArduino\USBMSC.cpp.o
Compiling .pio\build\dock_esp32\FrameworkArduino\WMath.cpp.o
Compiling .pio\build\dock_esp32\FrameworkArduino\WString.cpp.o
Compiling .pio\build\dock_esp32\FrameworkArduino\base64.cpp.o
Compiling .pio\build\dock_esp32\FrameworkArduino\cbuf.cpp.o
Compiling .pio\build\dock_esp32\FrameworkArduino\esp32-hal-adc.c.o
Compiling .pio\build\dock_esp32\FrameworkArduino\esp32-hal-bt.c.o
Compiling .pio\build\dock_esp32\FrameworkArduino\esp32-hal-cpu.c.o
Compiling .pio\build\dock_esp32\FrameworkArduino\esp32-hal-dac.c.o
Compiling .pio\build\dock_esp32\FrameworkArduino\esp32-hal-gpio.c.o
Compiling .pio\build\dock_esp32\FrameworkArduino\esp32-hal-i2c-slave.c.o
Compiling .pio\build\dock_esp32\FrameworkArduino\esp32-hal-i2c.c.o
Compiling .pio\build\dock_esp32\FrameworkArduino\esp32-hal-ledc.c.o
Compiling .pio\build\dock_esp32\FrameworkArduino\esp32-hal-matrix.c.o
Compiling .pio\build\dock_esp32\FrameworkArduino\esp32-hal-misc.c.o
Compiling .pio\build\dock_esp32\FrameworkArduino\esp32-hal-psram.c.o
Compiling .pio\build\dock_esp32\FrameworkArduino\esp32-hal-rgb-led.c.o
Compiling .pio\build\dock_esp32\FrameworkArduino\esp32-hal-rmt.c.o
Compiling .pio\build\dock_esp32\FrameworkArduino\esp32-hal-sigmadelta.c.o
Compiling .pio\build\dock_esp32\FrameworkArduino\esp32-hal-spi.c.o
Compiling .pio\build\dock_esp32\FrameworkArduino\esp32-hal-time.c.o
Compiling .pio\build\dock_esp32\FrameworkArduino\esp32-hal-timer.c.o
Compiling .pio\build\dock_esp32\FrameworkArduino\esp32-hal-tinyusb.c.o
Compiling .pio\build\dock_esp32\FrameworkArduino\esp32-hal-touch.c.o
Compiling .pio\build\dock_esp32\FrameworkArduino\esp32-hal-uart.c.o
Compiling .pio\build\dock_esp32\FrameworkArduino\firmware_msc_fat.c.o
Compiling .pio\build\dock_esp32\FrameworkArduino\libb64\cdecode.c.o
Compiling .pio\build\dock_esp32\FrameworkArduino\libb64\cencode.c.o
Compiling .pio\build\dock_esp32\FrameworkArduino\main.cpp.o
Compiling .pio\build\dock_esp32\FrameworkArduino\stdlib_noniso.c.o
Compiling .pio\build\dock_esp32\FrameworkArduino\wiring_pulse.c.o
Compiling .pio\build\dock_esp32\FrameworkArduino\wiring_shift.c.o
Archiving .pio\build\dock_esp32\libFrameworkArduino.a
Linking .pio\build\dock_esp32\firmware.elf
Retrieving maximum program size .pio\build\dock_esp32\firmware.elf
Checking size .pio\build\dock_esp32\firmware.elf
Advanced Memory Usage is available via "PlatformIO Home > Project Inspect"
RAM:   [==        ]  15.4% (used 50584 bytes from 327680 bytes)
Flash: [==        ]  24.3% (used 810529 bytes from 3342336 bytes)
Building .pio\build\dock_esp32\firmware.bin
esptool.py v4.11.0
Creating esp32s3 image...
Merged 2 ELF sections
Successfully created esp32s3 image.
========================= [SUCCESS] Took 75.21 seconds =========================

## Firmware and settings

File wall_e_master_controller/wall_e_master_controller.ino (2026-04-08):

// ============================================================
//  WALL-E Master Controller — CYD Direct-Draw UI
//  TFT_eSPI + XPT2046, no LVGL
//  State machine, animations, audio, zero-flicker
//  + Physical Joysticks (ADS1115) + Buttons (SX1509)
// ============================================================
//
// REQUIRED: TFT_eSPI (Setup_CYD_ESP32_2432S028R), XPT2046_Touchscreen
//           Adafruit_ADS1X15, SparkFun SX1509
//
// ============================================================

#include <Arduino.h>
#include <TFT_eSPI.h>
#include <esp_task_wdt.h>
#include <math.h>

#include "protocol.h"
#include "ui_draw.h"
#include "ui_state.h"
#include "touch_input.h"
#include "animation_system.h"
#include "audio_system.h"
#include "packet_control.h"
#include "espnow_control.h"

// Physical I2C input
#include "i2c_devices.h"
#include "ads1115_input.h"
#include "sx1509_input.h"

// Motion engine
#include "motion_engine.h"

// Emotion engine (poses + triggers; no servo output until wired)
#include "emotion_engine.h"

// Profile system
#include "profiles.h"

#include "command_queue.h"
#include "cyd_laser_ui.h"
#include "system_status.h"
#include "touch_handling.h"
#include "ui_rendering.h"
#include "command_input.h"

// SD card (SPI: CS 5, MOSI 23, MISO 19, SCK 18) + macro persistence
#include "sd_manager.h"
#include "macro_system.h"
#include "dev_console.h"
#include "ui_sd_explorer.h"
#include "sd_browser.h"

#define TFT_BL 21
#define WDT_TIMEOUT_SEC 3

TFT_eSPI tft = TFT_eSPI();

void setup() {
  Serial.begin(115200);
  delay(300);
  Serial.println("\n[WALL-E Master] CYD Command Console");

  // Configure watchdog timer (ESP-IDF 5.x API)
  esp_task_wdt_config_t wdt_config = {
    .timeout_ms = WDT_TIMEOUT_SEC * 1000,
    .idle_core_mask = 0,
    .trigger_panic = true
  };
  esp_task_wdt_init(&wdt_config);
  esp_task_wdt_add(NULL);
  Serial.printf("[WDT] Enabled (%ds timeout)\n", WDT_TIMEOUT_SEC);

  pinMode(TFT_BL, OUTPUT);
  digitalWrite(TFT_BL, HIGH);

  tft.init();
  tft.setRotation(1);

  // SD card: after TFT init (separate SPI bus). Macros + logs use SD when present.
  if (sdInit()) {
    sdLogInit();
    sdLog("WALL-E CYD Master boot");
    sdLogFlush();
  } else {
    sdLogInit();
  }
  macroInit();

  uiDrawInit(&tft);
  uiRenderingInit(&tft);
  uiStateInit();
  touchHandlingInit();
  commandQueueInit();
  cydLaserUiInit();
  systemStatusInit();
  commandInputInit();
  animInit();
  audioInit();
  packetInit();
  
  // Initialize motion engine
  motionInit();
  emotionInit();

  // Initialize profile system (loads from Preferences)
  profileInit();

  // Initialize I2C hardware
  i2cInit();
  i2cScan();
  
  bool ads_ok = ads1115Init();
  bool sx_ok = sx1509Init();
  
  if (!ads_ok || !sx_ok) {
    Serial.println(F("[WARN] Some I2C devices missing - check wiring"));
  }

  g_needStaticRedraw = true;

  Serial.println("[WALL-E Master] Ready");
}

void loop() {
  const uint32_t loopStartUs = micros();
  unsigned long now = millis();
  
  // Feed watchdog to prevent reset
  esp_task_wdt_reset();

  ads1115Update();
  sx1509Update();

  bool screenTouch = false;
  uint16_t sx = 0, sy = 0;
  if (touchGetTs()->touched()) {
    TS_Point tp = touchGetTs()->getPoint();
    sx = (uint16_t)constrain(map(tp.x, TOUCH_X_MIN, TOUCH_X_MAX, 0, 319), 0, 319);
    sy = (uint16_t)constrain(map(tp.y, TOUCH_Y_MIN, TOUCH_Y_MAX, 0, 239), 0, 239);
    screenTouch = true;
  }
  devConsoleProcessTouch(sx, sy, screenTouch);

  /* Right ~48px of banner only — avoids dev-console unlock hold (top-right x≈250–271) */
  const bool bannerTapZone =
      screenTouch && sy < (uint16_t)uiBannerTotalHeight() && sx >= (uint16_t)(SCREEN_W - 48);
  static bool s_prevBannerTapZone = false;
  if (!devConsoleIsUnlocked() && bannerTapZone && !s_prevBannerTapZone) {
    g_topBannerCollapsed = !g_topBannerCollapsed;
    uiBannerInvalidateTelemetryCache();
    g_needStaticRedraw = true;
    playUISound(SOUND_CLICK);
  }
  s_prevBannerTapZone = bannerTapZone;

  if (devConsoleIsUnlocked()) {
    commandQueueDrainAll();
    DriveState dsZ = {};
    motionSetHeadPanVelocity(0);
    motionSetHeadTiltVelocity(0);

    macroCheckJoystickOverride(false);
    float pbL, pbR, pbSv[9];
    if (macroGetPlaybackData(&pbL, &pbR, pbSv)) {
      dsZ.leftSpeed = (int8_t)constrain((int)lroundf(pbL), -100, 100);
      dsZ.rightSpeed = (int8_t)constrain((int)lroundf(pbR), -100, 100);
      for (int i = 0; i < 9; i++) {
        uint8_t deg = (uint8_t)constrain((int)lroundf(pbSv[i] * 180.0f / 100.0f), 0, 180);
        motionSetServoDirect(i, deg);
      }
    }
    if (!isDeadmanButtonHeld()) {
      dsZ.leftSpeed = 0;
      dsZ.rightSpeed = 0;
    }

    motionUpdate(now);

    uint8_t macTgt[10];
    motionGetServoTargets(macTgt);
    float macSv[9];
    for (int i = 0; i < 9; i++) {
      macSv[i] = macTgt[i] * (100.0f / 180.0f);
    }
    macroSetCurrentData((float)dsZ.leftSpeed, (float)dsZ.rightSpeed, macSv);
    macroUpdate(now);

    uint8_t st[10];
    motionGetServoTargets(st);
    float sv[9];
    for (int i = 0; i < 9; i++) {
      sv[i] = st[i] * (100.0f / 180.0f);
    }
    devConsoleFeedServoData(sv);
    TelemetryPacket tm;
    packetGetTelemetry(&tm);
    devConsoleFeedSensorData(tm.sonarDistanceCm, tm.compassHeading, tm.gpsValid != 0);
    devConsoleFeedPacketTiming(PACKET_SEND_INTERVAL_MS * 1000u, (uint32_t)(micros() - loopStartUs));
    devConsoleUpdate(now);
    devConsoleDraw(&tft);
    packetUpdate(now, &dsZ, g_estop);
    systemStatusTick(now);
    audioUpdate(now);
    sdUpdate();
    delay(1);
    return;
  }

  commandQueueDrainAll();

  int pageInt = (int)g_currentPage;
  TouchZone zone;
  if (bannerTapZone) {
    zone = TOUCH_ZONE_NONE;
  } else {
    zone = touchHandlingUpdate(pageInt);
  }

  static TouchZone s_prevTouchZone = TOUCH_ZONE_NONE;
  if (touchGetTs()->touched() && zone != TOUCH_ZONE_LASER_PAD && cydLaserUiIsDraggingHead()) {
    cydLaserUiCancelDrag();
  }
  if (!touchGetTs()->touched()) {
    cydLaserUiCancelDrag();
  }

  if (zone == TOUCH_ZONE_LASER_PAD && touchGetTs()->touched()) {
    TS_Point tp = touchGetTs()->getPoint();
    int screenX = map(tp.x, TOUCH_X_MIN, TOUCH_X_MAX, 0, 319);
    int screenY = map(tp.y, TOUCH_Y_MIN, TOUCH_Y_MAX, 0, 239);
    screenX = constrain(screenX, 0, 319);
    screenY = constrain(screenY, 0, 239);
    cydLaserUiDragFromScreen(screenX, screenY);
  }
  if (zone == TOUCH_ZONE_LASER_FIRE && s_prevTouchZone != TOUCH_ZONE_LASER_FIRE) {
    cydLaserUiToggleArmed();
    playUISound(SOUND_CLICK);
    Serial.println(F("[UI] Laser arm toggle"));
  }
  s_prevTouchZone = zone;

  DriveState ds;
  
  // Priority: Physical joystick overrides touch
  const JoystickState& joy = getJoystickState();
  bool joystickActive = joy.active[JOY2_X] || joy.active[JOY2_Y];
  bool joy1Active = joy.active[JOY1_X] || joy.active[JOY1_Y];

  if (joy1Active) {
    cydLaserUiCancelDrag();
  }

  if (cydLaserUiIsDraggingHead() && !joy1Active) {
    cydLaserUiApplyMotion();
  } else {
    motionSetHeadPanVelocity(joy.processed[JOY1_X]);
    motionSetHeadTiltVelocity(joy.processed[JOY1_Y]);
  }
  
  // DRIVE CONTROL (Joy2) - tank drive
  if (joystickActive) {
    joystickToDriveState(&ds);
    
    // Log drive state when joystick is active
    static unsigned long lastJoyLog = 0;
    if (now - lastJoyLog > 500) {  // Every 500ms
      Serial.printf("[Drive] Joystick: L=%d%% R=%d%% (Deadman: %s)\n", 
        ds.leftSpeed, ds.rightSpeed, isDeadmanButtonHeld() ? "HELD" : "NOT HELD");
      lastJoyLog = now;
    }
  } else {
    touchGetDriveState(&ds);
  }

  commandQueueApplyDriveOverride(&ds, joystickActive);

  // CRITICAL: DEADMAN BUTTON CHECK - Must be held to move TRACKS ONLY!
  // Servos, head, animations work WITHOUT deadman!
  if (!isDeadmanButtonHeld()) {
    ds.leftSpeed = 0;
    ds.rightSpeed = 0;
    static unsigned long lastDeadmanWarning = 0;
    if (now - lastDeadmanWarning > 2000 && joystickActive) {
      Serial.println("[DEADMAN] Button not held - TRACKS disabled! (servos/head still work)");
      lastDeadmanWarning = now;
    }
  }

  // Safety lock: no touch for 200ms → STOP (only if joystick also inactive)
  if (!joystickActive && (now - touchLastActivityMs() > PACKET_SAFETY_TIMEOUT_MS)) {
    ds.leftSpeed = 0;
    ds.rightSpeed = 0;
  }

  // Zone actions — E-STOP: tap to trigger, tap again to clear
  if (zone == TOUCH_ZONE_ESTOP) {
    g_estop = !g_estop;
    if (g_estop) {
      ds.leftSpeed = 0;
      ds.rightSpeed = 0;
      g_controlAuthority = CTRL_SAFETY;
      playUISound(SOUND_ESTOP);
    } else {
      g_controlAuthority = CTRL_LOCAL;
      playUISound(SOUND_CLICK);
    }
  }
  if (zone == TOUCH_ZONE_NAV_BEHAV) {
    g_currentPage = PAGE_BEHAVIOUR;
    g_needStaticRedraw = true;
    playUISound(SOUND_CLICK);
  }
  if (zone == TOUCH_ZONE_NAV_SYSTEM) {
    g_currentPage = PAGE_SYSTEM;
    g_needStaticRedraw = true;
    playUISound(SOUND_CLICK);
  }
  if (zone == TOUCH_ZONE_NAV_BACK) {
    if (g_currentPage == PAGE_HELP && g_helpSection > 0) {
      g_helpSection = 0;
    } else if (g_currentPage == PAGE_HELP) {
      g_currentPage = PAGE_SYSTEM;
      g_helpSection = 0;
    } else {
      g_currentPage = PAGE_DRIVE;
    }
    g_needStaticRedraw = true;
    playUISound(SOUND_CLICK);
  }
  if (zone == TOUCH_ZONE_NAV_PROFILE) {
    g_currentPage = PAGE_PROFILE;
    g_needStaticRedraw = true;
    playUISound(SOUND_CLICK);
  }
  if (zone == TOUCH_ZONE_NAV_SERVO_TEST) {
    g_currentPage = PAGE_SERVO_TEST;
    g_needStaticRedraw = true;
    playUISound(SOUND_CLICK);
  }
  if (zone == TOUCH_ZONE_DOCK_GO) {
    packetSetPendingAction(ACTION_DOCK_GO);
    playUISound(SOUND_MODE_CHANGE);
    Serial.println(F("[Dock] Go to dock"));
  }
  if (zone == TOUCH_ZONE_DOCK_CANCEL) {
    packetSetPendingAction(ACTION_DOCK_CANCEL);
    playUISound(SOUND_CLICK);
    Serial.println(F("[Dock] Cancel"));
  }
  if (zone == TOUCH_ZONE_QUICK_ACTION) {
    g_overlayVisible = !g_overlayVisible;
    g_needStaticRedraw = true;
    playUISound(SOUND_MODE_CHANGE);
  }
  if (zone == TOUCH_ZONE_ADVANCED) {
    g_advancedMode = !g_advancedMode;
    playUISound(SOUND_CONFIRM);
  }
  // NEW: Autonomy navigation
  if (zone == TOUCH_ZONE_NAV_AUTONOMY) {
    g_currentPage = PAGE_AUTONOMY;
    g_autonomyUiTab = 0;
    g_needStaticRedraw = true;
    playUISound(SOUND_CLICK);
    Serial.println(F("[Nav] Navigated to Autonomy page"));
  }
  if (zone == TOUCH_ZONE_NAV_HELP) {
    g_currentPage = PAGE_HELP;
    g_helpSection = 0;
    g_needStaticRedraw = true;
    playUISound(SOUND_CLICK);
    Serial.println(F("[Nav] Help"));
  }
  if (zone >= TOUCH_ZONE_HELP_TOPIC_0 && zone <= TOUCH_ZONE_HELP_TOPIC_3) {
    g_helpSection = (uint8_t)(1 + (zone - TOUCH_ZONE_HELP_TOPIC_0));
    g_needStaticRedraw = true;
    playUISound(SOUND_CLICK);
    Serial.printf("[Nav] Help topic %u\n", (unsigned)g_helpSection);
  }
  if (zone == TOUCH_ZONE_NAV_SD) {
    uiSdExplorerClosePreview();
    uiSdExplorerCloseConfirm();
    uiSdExplorerCloseRename();
    sdBrowserOnEnterPage();
    g_currentPage = PAGE_SD_EXPLORER;
    g_needStaticRedraw = true;
    playUISound(SOUND_CLICK);
    Serial.println(F("[Nav] SD explorer"));
  }
  if (zone >= TOUCH_ZONE_MC_SC_0 && zone <= TOUCH_ZONE_MC_SC_5) {
    static const char* const kMemCorePath[] = {
      SD_MEMORY_DIR,
      SD_LOGS,
      SD_CONFIG_DIR,
      SD_MISSIONS_DIR,
      SD_DIAG_DIR,
      SD_EVENTS_DIR
    };
    int si = (int)(zone - TOUCH_ZONE_MC_SC_0);
    if (sdBrowserNavigateToAbsolute(kMemCorePath[si])) {
      Serial.printf("[MemCore] Shortcut -> %s\n", kMemCorePath[si]);
    } else {
      Serial.printf("[MemCore] Shortcut failed: %s\n", kMemCorePath[si]);
    }
    g_needStaticRedraw = true;
    playUISound(SOUND_CLICK);
  }
  if (zone >= TOUCH_ZONE_SD_LIST_0 && zone <= TOUCH_ZONE_SD_LIST_3) {
    int row = (int)(zone - TOUCH_ZONE_SD_LIST_0);
    uint16_t idx = (uint16_t)(sdBrowserGetScroll() + (uint16_t)row);
    sdBrowserSetSelected((int16_t)idx);
    g_needStaticRedraw = true;
    playUISound(SOUND_CLICK);
  }
  if (zone == TOUCH_ZONE_SD_UP) {
    sdBrowserGoUp();
    g_needStaticRedraw = true;
    playUISound(SOUND_CLICK);
  }
  if (zone == TOUCH_ZONE_SD_OPEN) {
    if (sdBrowserGetSelected() >= 0) {
      const SdDirEntry* e = sdBrowserGetEntry((uint16_t)sdBrowserGetSelected());
      if (e && e->isDir) {
        sdBrowserEnterSelected();
      } else if (e) {
        uiSdExplorerTryOpenPreview();
      }
    }
    g_needStaticRedraw = true;
    playUISound(SOUND_CLICK);
  }
  if (zone == TOUCH_ZONE_SD_REFRESH) {
    sdBrowserRefresh();
    g_needStaticRedraw = true;
    playUISound(SOUND_CLICK);
  }
  if (zone == TOUCH_ZONE_SD_PG_PREV) {
    uint16_t sc = sdBrowserGetScroll();
    if (sc >= SD_BROWSER_VISIBLE_ROWS) {
      sdBrowserSetScroll((uint16_t)(sc - SD_BROWSER_VISIBLE_ROWS));
    } else {
      sdBrowserSetScroll(0);
    }
    g_needStaticRedraw = true;
    playUISound(SOUND_CLICK);
  }
  if (zone == TOUCH_ZONE_SD_PG_NEXT) {
    uint16_t sc = sdBrowserGetScroll();
    uint16_t cnt = sdBrowserGetEntryCount();
    uint16_t maxScr = (cnt > SD_BROWSER_VISIBLE_ROWS) ? (uint16_t)(cnt - SD_BROWSER_VISIBLE_ROWS) : 0;
    uint16_t nsc = (uint16_t)(sc + SD_BROWSER_VISIBLE_ROWS);
    if (nsc > maxScr) nsc = maxScr;
    sdBrowserSetScroll(nsc);
    g_needStaticRedraw = true;
    playUISound(SOUND_CLICK);
  }
  if (zone == TOUCH_ZONE_SD_DELETE) {
    uiSdExplorerRequestDeleteConfirm();
    g_needStaticRedraw = true;
    playUISound(SOUND_CLICK);
  }
  if (zone == TOUCH_ZONE_SD_CONFIRM_YES) {
    if (sdBrowserDeleteSelected()) {
      uiSdExplorerCloseConfirm();
    }
    g_needStaticRedraw = true;
    playUISound(SOUND_CLICK);
  }
  if (zone == TOUCH_ZONE_SD_CONFIRM_NO) {
    uiSdExplorerCloseConfirm();
    g_needStaticRedraw = true;
    playUISound(SOUND_CLICK);
  }
  if (zone == TOUCH_ZONE_SD_RENAME) {
    uiSdExplorerRequestRename();
    g_needStaticRedraw = true;
    playUISound(SOUND_CLICK);
  }
  if (zone == TOUCH_ZONE_SD_RENAME_CH_DEC) {
    uiSdExplorerRenameChrDec();
    g_needStaticRedraw = true;
    playUISound(SOUND_CLICK);
  }
  if (zone == TOUCH_ZONE_SD_RENAME_CH_INC) {
    uiSdExplorerRenameChrInc();
    g_needStaticRedraw = true;
    playUISound(SOUND_CLICK);
  }
  if (zone == TOUCH_ZONE_SD_RENAME_BKSP) {
    uiSdExplorerRenameBksp();
    g_needStaticRedraw = true;
    playUISound(SOUND_CLICK);
  }
  if (zone == TOUCH_ZONE_SD_RENAME_CUR_L) {
    uiSdExplorerRenameCurLeft();
    g_needStaticRedraw = true;
    playUISound(SOUND_CLICK);
  }
  if (zone == TOUCH_ZONE_SD_RENAME_CUR_R) {
    uiSdExplorerRenameCurRight();
    g_needStaticRedraw = true;
    playUISound(SOUND_CLICK);
  }
  if (zone == TOUCH_ZONE_SD_RENAME_CANCEL) {
    uiSdExplorerCloseRename();
    g_needStaticRedraw = true;
    playUISound(SOUND_CLICK);
  }
  if (zone == TOUCH_ZONE_SD_RENAME_OK) {
    uiSdExplorerRenameApplyOk();
    g_needStaticRedraw = true;
    playUISound(SOUND_CLICK);
  }
  if (zone == TOUCH_ZONE_AUTONOMY_TAB_LIVE) {
    g_autonomyUiTab = 0;
    g_needStaticRedraw = true;
    playUISound(SOUND_CLICK);
  }
  if (zone == TOUCH_ZONE_AUTONOMY_TAB_TUNE) {
    g_autonomyUiTab = 1;
    g_needStaticRedraw = true;
    playUISound(SOUND_CLICK);
  }
  if (zone == TOUCH_ZONE_AUTONOMY_ARM) {
    g_remoteAutonomyArm = !g_remoteAutonomyArm;
    g_needStaticRedraw = true;
    playUISound(SOUND_MODE_CHANGE);
    Serial.printf("[Autonomy] ARM TX %s\n", g_remoteAutonomyArm ? "ON" : "off");
  }
  if (zone == TOUCH_ZONE_AUTONOMY_M_CLOSE) {
    if (g_auCloseCm > 10) g_auCloseCm -= 5;
    if (g_auInterestCm < (uint8_t)(g_auCloseCm + 5)) g_auInterestCm = g_auCloseCm + 5;
    packetSetAutonomyConfig(AUTONOMY_KEY_DETECT_CLOSE_CM, g_auCloseCm);
    g_needStaticRedraw = true;
    playUISound(SOUND_CLICK);
  }
  if (zone == TOUCH_ZONE_AUTONOMY_P_CLOSE) {
    if (g_auCloseCm < 150) g_auCloseCm += 5;
    if (g_auInterestCm < (uint8_t)(g_auCloseCm + 5)) g_auInterestCm = g_auCloseCm + 5;
    packetSetAutonomyConfig(AUTONOMY_KEY_DETECT_CLOSE_CM, g_auCloseCm);
    g_needStaticRedraw = true;
    playUISound(SOUND_CLICK);
  }
  if (zone == TOUCH_ZONE_AUTONOMY_M_INT) {
    uint8_t lo = g_auCloseCm + 5;
    if (g_auInterestCm > lo) g_auInterestCm -= 5;
    packetSetAutonomyConfig(AUTONOMY_KEY_DETECT_INTEREST_CM, g_auInterestCm);
    g_needStaticRedraw = true;
    playUISound(SOUND_CLICK);
  }
  if (zone == TOUCH_ZONE_AUTONOMY_P_INT) {
    if (g_auInterestCm < 200) g_auInterestCm += 5;
    packetSetAutonomyConfig(AUTONOMY_KEY_DETECT_INTEREST_CM, g_auInterestCm);
    g_needStaticRedraw = true;
    playUISound(SOUND_CLICK);
  }
  if (zone == TOUCH_ZONE_AUTONOMY_M_CUR) {
    if (g_auCuriosityPct > 0) g_auCuriosityPct -= 5;
    packetSetAutonomyConfig(AUTONOMY_KEY_CURIOSITY, g_auCuriosityPct);
    g_needStaticRedraw = true;
    playUISound(SOUND_CLICK);
  }
  if (zone == TOUCH_ZONE_AUTONOMY_P_CUR) {
    if (g_auCuriosityPct < 100) g_auCuriosityPct += 5;
    packetSetAutonomyConfig(AUTONOMY_KEY_CURIOSITY, g_auCuriosityPct);
    g_needStaticRedraw = true;
    playUISound(SOUND_CLICK);
  }
  if (zone == TOUCH_ZONE_AUTONOMY_M_BRV) {
    if (g_auBraveryPct > 0) g_auBraveryPct -= 5;
    packetSetAutonomyConfig(AUTONOMY_KEY_BRAVERY, g_auBraveryPct);
    g_needStaticRedraw = true;
    playUISound(SOUND_CLICK);
  }
  if (zone == TOUCH_ZONE_AUTONOMY_P_BRV) {
    if (g_auBraveryPct < 100) g_auBraveryPct += 5;
    packetSetAutonomyConfig(AUTONOMY_KEY_BRAVERY, g_auBraveryPct);
    g_needStaticRedraw = true;
    playUISound(SOUND_CLICK);
  }
  if (zone == TOUCH_ZONE_AUTONOMY_WAYPOINT) {
    g_auWaypointFollow = !g_auWaypointFollow;
    packetSetAutonomyConfig(AUTONOMY_KEY_WAYPOINT_MODE, g_auWaypointFollow ? 1u : 0u);
    g_needStaticRedraw = true;
    playUISound(SOUND_MODE_CHANGE);
  }
  if (zone == TOUCH_ZONE_AUTONOMY_PRESET_0) {
    packetSetAutonomyConfig(AUTONOMY_KEY_PRESET, 0);
    g_needStaticRedraw = true;
    playUISound(SOUND_CONFIRM);
  }
  if (zone == TOUCH_ZONE_AUTONOMY_PRESET_1) {
    packetSetAutonomyConfig(AUTONOMY_KEY_PRESET, 1);
    g_needStaticRedraw = true;
    playUISound(SOUND_CONFIRM);
  }
  if (zone == TOUCH_ZONE_AUTONOMY_PRESET_2) {
    packetSetAutonomyConfig(AUTONOMY_KEY_PRESET, 2);
    g_needStaticRedraw = true;
    playUISound(SOUND_CONFIRM);
  }
  if (zone == TOUCH_ZONE_AUTONOMY_PRESET_3) {
    packetSetAutonomyConfig(AUTONOMY_KEY_PRESET, 3);
    g_needStaticRedraw = true;
    playUISound(SOUND_CONFIRM);
  }
  if (zone == TOUCH_ZONE_PROFILE_0) {
    profileSet(0);
    playUISound(SOUND_MODE_CHANGE);
    g_needStaticRedraw = true;  // Force UI redraw
    Serial.println(F("[Profile] Switched to Kid mode"));
  }
  if (zone == TOUCH_ZONE_PROFILE_1) {
    profileSet(1);
    playUISound(SOUND_MODE_CHANGE);
    g_needStaticRedraw = true;  // Force UI redraw
    Serial.println(F("[Profile] Switched to Demo mode"));
  }
  if (zone == TOUCH_ZONE_PROFILE_2) {
    profileSet(2);
    playUISound(SOUND_MODE_CHANGE);
    g_needStaticRedraw = true;  // Force UI redraw
    Serial.println(F("[Profile] Switched to Advanced mode"));
  }
  if (zone == TOUCH_ZONE_PROFILE_EDIT_0 || zone == TOUCH_ZONE_PROFILE_EDIT_1 || zone == TOUCH_ZONE_PROFILE_EDIT_2) {
    // Set profile first before entering editor
    uint8_t profileId = zone - TOUCH_ZONE_PROFILE_EDIT_0;
    profileSet(profileId);
    g_currentPage = PAGE_SERVO_EDITOR;
    g_needStaticRedraw = true;
    playUISound(SOUND_CLICK);
    Serial.printf("[ServoEdit] Editing %s profile\n", profileGet()->name);
  }
  if (zone == TOUCH_ZONE_SERVO_SAVE) {
    profileSave();
    playUISound(SOUND_CONFIRM);
    Serial.println(F("[ServoEdit] Settings saved to flash"));
  }
  if (zone == TOUCH_ZONE_SERVO_RESET) {
    profileApply();  // Re-apply current profile (resets any unsaved changes)
    g_needStaticRedraw = true;
    playUISound(SOUND_CLICK);
    Serial.println(F("[ServoEdit] Settings reset"));
  }
  // Slider drag handling
  if (zone >= TOUCH_ZONE_SLIDER_0 && zone <= TOUCH_ZONE_SLIDER_4) {
    // Touch on a slider - handle drag
    XPT2046_Touchscreen* ts = touchGetTs();
    if (ts->touched()) {
      TS_Point p = ts->getPoint();
      int screenX = map(p.x, 200, 3700, 0, 319);
      screenX = constrain(screenX, 0, 319);
      
      // Calculate slider value from X position (120-300 = slider area)
      const int sliderX = 120;
      const int sliderW = 180;
      float sliderValue = (float)(screenX - sliderX) / (float)sliderW;
      sliderValue = constrain(sliderValue, 0.0f, 1.0f);
      
      uint8_t sliderIndex = zone - TOUCH_ZONE_SLIDER_0;
      
      switch (sliderIndex) {
        case 0:  // Head sensitivity (0.5-2.0 range)
          {
            float newVal = 0.5f + (sliderValue * 1.5f);
            Profile* p = profileGet();
            profileAdjustHeadSensitivity(newVal - p->headSensitivity);
          }
          break;
        case 1:  // Servo speed (0-1.0)
          profileAdjustServoSpeed(sliderValue - profileGet()->servoSpeedLimit);
          break;
        case 2:  // Deadzone (0-0.5)
          profileAdjustDeadzone((sliderValue * 0.5f) - profileGet()->joystickDeadzone);
          break;
        case 3:  // Expo (0-1.0)
          profileAdjustExpo(sliderValue - profileGet()->joystickExpo);
          break;
        case 4:  // Max speed (0-1.0)
          profileAdjustMaxSpeed(sliderValue - profileGet()->joystickMaxSpeed);
          break;
      }
      
      g_needStaticRedraw = true;  // Redraw to show new slider position
    }
  }
  // Servo test page - individual servo sliders
  if (zone >= TOUCH_ZONE_SERVO_SLIDER_0 && zone <= TOUCH_ZONE_SERVO_SLIDER_9) {
    XPT2046_Touchscreen* ts = touchGetTs();
    if (ts->touched()) {
      TS_Point p = ts->getPoint();
      int screenX = map(p.x, 200, 3700, 0, 319);
      screenX = constrain(screenX, 0, 319);
      
      uint8_t servoIndex = zone - TOUCH_ZONE_SERVO_SLIDER_0;
      
      // Calculate servo position from X (slider is 90px wide, represents 0-180°)
      int col = (servoIndex < 5) ? 10 : 165;
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

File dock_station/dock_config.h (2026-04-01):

/*******************************************************************************
 * dock_config.h
 * Pin definitions and compile-time configuration for Smart Charging Crate
 ******************************************************************************/

#ifndef DOCK_CONFIG_H
#define DOCK_CONFIG_H

/*=============================================================================
 * PIN DEFINITIONS (ESP32-S3 DevKit-style board)
 * NOTE: These GPIO numbers follow the original ESP32-WROOM-32 layout.
 *       Verify against your specific ESP32-S3 N16R8 carrier board and
 *       adjust if any peripherals are wired to different pins.
 *
 * PIN SUMMARY (one function per GPIO — no clashes):
 *   GPIO  1  ACS712 current sense (ADC)
 *   GPIO  2  NeoPixel data (WS2812B)
 *   GPIO  4  Charge MOSFET gate
 *   GPIO  5  Alignment right (IR input)
 *   GPIO  6  PIR / motion sensor (charging bay presence — OR’d into dock detect)
 *   GPIO  8  TFT CS (chip select)
 *   GPIO  9   (free)
 *   GPIO 10  Alignment left (IR input)
 *   GPIO 13  Obstacle front right
 *   GPIO 14  Obstacle front left
 *   GPIO 15  Call WALL-E switch
 *   GPIO 16  Obstacle back left
 *   GPIO 17  Obstacle back right
 *   GPIO 18  Arrow right MOSFET
 *   GPIO 19  Arrow left MOSFET
 *   GPIO 21  Internal LED MOSFET
 *
 *   GPIO  3  TFT DC    GPIO  7  TFT RST   GPIO 11  TFT MOSI (SPI)
 *   GPIO 12  TFT SCK   GPIO 20  TFT BL (LED)
 *   GPIO  9  VL6180 SDA (I2C)  GPIO 47  VL6180 SCL — if USE_VL6180_TOF
 * FREE: adjust 9/47 if you need those pins elsewhere.
 *===========================================================================*/

#define PIN_MOSFET_GATE      4   /* Charge enable MOSFET gate (GPIO4: output-capable on ESP32-S3) */
#define PIN_ACS712_ADC       1   /* ACS712 analog out (GPIO1: ADC-capable on ESP32-S3) */
/** Digital motion sensor (PIR etc.) on GPIO6 — “presence” for dock/charging state machine (OR with ToF/sonar/obstacles). */
#define PIN_MOTION_SENSOR    6
#define PIN_IR_BEAM          PIN_MOTION_SENSOR   /* legacy name */
/* 1 = motion when pin reads HIGH (typ. HC-SR501); 0 = motion when LOW */
#define MOTION_ACTIVE_HIGH   1
#define MOTION_DEBOUNCE_MS   60
/* Obstacle sensors — positions when looking at the dock box from the front */
#define PIN_OBSTACLE_1      14   /* Front left  (GPIO14) */
#define PIN_OBSTACLE_2      13   /* Front right (GPIO13) */
#define PIN_OBSTACLE_3      16   /* Back left   (GPIO16) */
#define PIN_OBSTACLE_4      17   /* Back right  (GPIO17) */
#define PIN_STATUS_NEOPIXEL  2
#define NEOPIXEL_STRIP_COUNT  10   /* Status strip (indices 0..9) */
#define NEOPIXEL_FAULT_LED_INDEX  10  /* Single NeoPixel on same data line = status LED (11th LED) */
#define NEOPIXEL_COUNT  (NEOPIXEL_STRIP_COUNT + 1)   /* 11 total: strip + status LED */

/* Status LED (10): green = all good (WALL-E docked, mouth clear), flash orange = sensor triggered (waiting/mouth blocked), red = fault. */
#define NEOPIXEL_STATUS_LED_LINK_FAULT  1   /* 1 = solid red when dock in FAULT */
#define NEOPIXEL_STATUS_LED_LINK_BEAM   1   /* 1 = green when docked + clear; else contributes to flash orange */
#define NEOPIXEL_STATUS_LED_LINK_MOUTH  1   /* 1 = mouth blocked → flash orange; clear required for green */
#define NEOPIXEL_STATUS_LED_ORANGE_FLASH_MS  500   /* Orange flash half-period (on/off) when sensor triggered */

/* Sensor / charging indicator layout (pixels linked to each sensor + loading bar) */
#define NEOPIXEL_BEAM_FIRST    0   /* first pixel of beam pair (0-1) */
#define NEOPIXEL_BEAM_COUNT    2   /* beam: green = present, red = not present */
#define NEOPIXEL_MOUTH_FIRST   2   /* first pixel of mouth pair (2-3) */
#define NEOPIXEL_MOUTH_COUNT   2   /* mouth/obstacles: green = clear, red = blocked */
#define NEOPIXEL_CHARGE_FIRST  4   /* first pixel of charging/load bar (4-9) */
#define NEOPIXEL_CHARGE_COUNT  6   /* bar fills as loading/charging progresses; green when charged */

/* Call WALL-E push button (INPUT_PULLUP: LOW = pressed). Press to start callout; stops when WALL-E docks or press again. */
#define PIN_CALL_SWITCH   15   /* avoid GPIO 0 (boot) */

/* Dock alignment — dual TSOP/VS1838B receivers (see dock_ir_guidance).
 *   WALL-E base firmware drives two modulated IR TX toward these (dock_ir_transmitters.h).
 *   Receiver output: LOW = IR seen, HIGH = idle. Not mixed with break-beam (PIN_IR_BEAM).
 */
#define PIN_ALIGN_LEFT    10   /* Left side of bay: IR receiver digital OUT */
#define PIN_ALIGN_RIGHT    5   /* Right side of bay: IR receiver digital OUT */

/* Arrow indicator MOSFET outputs (guide WALL-E left/right) */
#define PIN_ARROW_LEFT    19   /* 16 not broken out on this module */
#define PIN_ARROW_RIGHT   18   /* 17 not broken out on this module */

/* Internal LED (MOSFET) — e.g. dock interior lighting */
#define PIN_INTERNAL_LED  21

/* MOSFET module logic: 1 = active LOW (LOW = load ON). Try 0 if still no output. */
#define MOSFET_ARROW_ACTIVE_LOW    1
#define MOSFET_INTERNAL_ACTIVE_LOW 1
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

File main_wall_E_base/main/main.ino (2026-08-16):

// ============================================================
// Arduino IDE: open this folder ("main") and main.ino.
// WALL-E Base Brain — ESP32-S3 production target
// Motor: L298N Dual H-Bridge
// Radio: native Wi-Fi / ESP-NOW on the Base S3
// ============================================================

#include <Arduino.h>
#include "motor_control.h"
#include "wifi_manager.h"
#include "web_server.h"
#include "display_manager.h"
#include "servo_manager.h"
#include "imu_manager.h"
#include "battery_monitor.h"
#include "flashlight_control.h"
#include "espnow_receiver.h"
#include "vl53l1x_tof.h"
#include "dock_sensors.h"
#include "dock_homing.h"
#include "autonomous_docking.h"
#include "dock_controller.h"
#include "dock_ir_transmitters.h"
#include "dock_config.h"
#include "vision_behaviour.h"
#include "audio_espnow.h"
#include "node_health_registry.h"
#include "walle_emotion_pose_bridge.h"
#include "walle_emotion_pose.h"

#include "sonar_sensor.h"
#include "compass_sensor.h"
#include "gps_module.h"
#include "waypoint_nav.h"
#include "personality_engine.h"
#include "emotion_engine.h"
#include "interest_engine.h"
#include "memory_engine.h"
#include "return_home_engine.h"
#include "autonomy_engine.h"
#include "unified_autonomy_engine.h"
#include "motion_layer.h"
#include "motion_authority.h"
#include "api_security.h"
#include "eve_uart_bridge.h"
#include "laser_control.h"
#include "sequence_engine.h"

#define FAILSAFE_TIMEOUT_MS 500UL

unsigned long lastCommandMillis = 0;

void setup() {
  Serial.begin(115200);
  delay(200);
  Serial.println("\n[WALL-E/S3] Starting Base Brain...");

  // Motors safe first — always.
  motorInit();
  motionLayerInit();
  Serial.println("[Motors] Initialised");

  displayInit();

  // Shared I2C bus: PCA9685 starts the bus; IMU follows.
  servoInit();
  servoNeutral(SERVO_SLOW_SPEED);
  beginIMU();
  Serial.println("[IMU] Init complete");

  // Effects start in a deterministic safe state before any remote command can
  // arrive. laserInit() attaches PWM and forces the output OFF.
  laserInit();

  // Autonomy stack. Optional sensors fail gracefully.
  if (!sonarInit()) Serial.println(F("[Sonar] WARN: init failed"));
  else Serial.println(F("[Sonar] Ready"));

  if (!compassInit()) Serial.println(F("[Compass] WARN: not available (continuing)"));
  else Serial.println(F("[Compass] Ready"));

  if (!gpsInit()) Serial.println(F("[GPS] WARN: init failed"));
  else Serial.println(F("[GPS] Ready"));

  waypointInit();
  personalityInit();
  emotionInit();
  interestInit();
  memoryInit();
  returnHomeInit();
  autonomyInit();
  unifiedAutonomyInit();
  Serial.println(F("[Autonomy] Engine ready"));

  batteryInit();
  displayUpdateBattery();

  dockSensorsBegin();

  // The Base S3 owns Wi-Fi directly. ESP-NOW uses the same radio hardware,
  // while radio_transport keeps packet ownership in one place.
  wifiManagerInit();
  displayUpdateWifi();

  motionAuthorityInit();
  apiSecurityInit();
  eveUartBridgeInit();

  // Sequence persistence/state exists independently of the HTTP API, so
  // initialize the engine before registering WebUI routes.
  sequenceEngineInit();
  webServerInit();

  // Native ESP-NOW receive/send abstraction on the Base S3.
  espnowReceiverInit();
  audioEspNowInit();
  nodeHealthInit();
  walleEmotionPoseBridgeInit();

  visionBehaviourInit();
  dockControllerInit();
  dockIrTransmittersInit();
  autonomousDockingInit();
  flashlightInit();

  lastCommandMillis = millis();
  Serial.println("[WALL-E/S3] Ready");
}

unsigned long lastTelemSendMs = 0;
#define TELEM_SEND_INTERVAL_MS 100
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

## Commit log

2026-03-01 feat: Add complete autonomous navigation system with GPS waypoints
    Major Features:
    - Full autonomous AI engine with 11-state behavior machine
    - GPS waypoint navigation with Haversine distance calculation
    - Ultrasonic sonar obstacle detection (non-blocking)
    - Electronic compass (HMC5883L/QMC5883L) for heading awareness
    - Real-time telemetry display on CYD controller
    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
2026-03-02 refactor: Update motion engine and touch input for clarity and ESP32-S3 compatibility
    Changes:
    - Clarified comments in motion_engine.cpp to specify the number of servos.
    - Removed unused servo references in neutral positions.
    - Updated test pose comments to reflect the use of 9 servos.
    - Adjusted touch_input.cpp to define SPI class for ESP32-S3 compatibility.
2026-03-09 Base+Controller: ESP-NOW broadcast, E-STOP toggle, UI fixes, battery calibration (5V rail 4.91V)
    Made-with: Cursor
    [815 Servo Driver 16 Channel.stl, BracketLock_ESP32_36pin.stl, Bracket_ESP32_36pin.stl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]
2026-03-23 Wall-E firmware: dock station, base, audio_esp, web UI; remove legacy audio assets
    - Dock station: sensors, ESP-NOW, alignment, display, VL6180/sonar
    - Main base: autonomous docking, audio ESP-NOW/telem, web console split
    - Add audio_esp companion firmware and webui
    - Remove wall_e_audio WAV bundle and wall_e_audio_voice managed components
    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
    [partitions.csv]
2026-04-01 LROS web UI More pages polish; vision/navigation stack; dock & autonomy updates
    - Web: subpage deck styling, embedded web_page_lros.h, JS modules and standalone sync
    - Base: navigation API, unified autonomy, laser control, dock IR transmitters, web server
    - Vision: colour/blob/recognition pipeline; motion detect updates
    - Dock station, CYD master controller, docs and mounts assets
    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
    [1.3 TFT IPS - 24 Pin - Socket Flat.stp, 1.3 TFT IPS - 24 Pin - Socket Revers Mount.stp, 1.3 TFT IPS - Assortment.cfg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]
2026-04-08 Memory Core SD browser, LROS web updates, base motion/sequence/EVE
    - CYD: SD Memory Core (browse, preview, delete, rename modal), prefs cwd,
    truncated dir listing with yield; sd_browser/sd_actions/file_preview modules
    - Base: motion authority/layer, sequence engine/API, EVE UART bridge, API security
    - WebUI: LROS map/sequences JS, embedded HTML/CSS updates
    - Docs: eve_hardware; add eve/ and ghostbusters_slime_blower sketches
    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
    [Meshy_AI_Blue-Eyed Droid_1775645156_generate.3mf]
2026-04-08 chore: ignore loose CAD/reference at repo root; remove touch Serial debug
    - .gitignore: root stl/stp/step/webp, Eve export folder, legacy bluetooth copy
    - touch_input: drop periodic touch + nav Serial spam
    - Memory Core rename modal: shorter hint line
    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
2026-04-19 feat: add EVE battery/power monitoring and WALL-E telemetry integration
    - eve/include/config.h: add EVE_BAT_VOLT_ADC_PIN, EVE_BAT_CURR_ADC_PIN,
    EVE_CHARGER_PRESENT_PIN, EVE_ENABLE_POWER_MONITOR, EVE_POWER_STATUS_INTERVAL_MS
    - eve/include/eve_protocol.h: add MSG_EVE_POWER_STATUS = 0x08
    - eve/include/power_monitor.h: BatteryState enum, PowerStatus struct, full public API
    - eve/src/power_monitor.cpp: ADC reads with EMA+MA filtering, battery state
    machine with hysteresis, local NeoPixel reaction hooks
    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
2026-04-19 fix: address code review - charging detection uses < not <=, document millis wraparound safety
    Agent-Logs-Url: https://github.com/sumkindafreak/wall-e/sessions/c60beeb6-1935-436c-aae5-bccda93d9993
2026-08-16 fix telemetry wire size guard
    [walle_control_protocol.h]
2026-08-16 name servo wire slots explicitly
2026-08-16 align master servo slots with Base hardware
2026-08-16 map CYD servo slots to physical Base channels
2026-08-16 centralize ESP32-P4 Base pin map
2026-08-16 use centralized Base motor pins
2026-08-16 use centralized Base I2C pins
2026-08-16 use centralized Base ADC pins
2026-08-16 use centralized Base laser pin
2026-08-16 use centralized Base sonar pins
2026-08-16 use centralized Base GPS UART pins
2026-08-16 bind P4 radio UART to board pin map
2026-08-16 use headless display backend on ESP32-P4
2026-08-16 compile P4 with UART Serial path
2026-08-16 separate P4 radio and GPS UART peripherals
2026-08-16 document WALL-E Waveshare P4 wiring
2026-08-16 avoid P4 hosted WiFi and low-voltage GPIO conflicts
    [base_board_pins.h]
2026-08-16 document final P4 pin and I2C expander map
2026-08-16 add Arduino 2.x/3.x LEDC compatibility layer
2026-08-16 make motor PWM compile on Arduino ESP32 2.x and 3.x
2026-08-16 make laser PWM compile on Arduino ESP32 2.x and 3.x
2026-08-16 make dock IR PWM compile on Arduino ESP32 2.x and 3.x
2026-08-16 fix ESP32-C6 Arduino 3.3 ESP-NOW callback
2026-08-16 bridge legacy display LEDC calls on Arduino 2.x
2026-08-16 support ESP-NOW receive callbacks on Arduino 2.x and 3.x
2026-08-16 fix GPS diagnostics and P4 RX-only UART
    [gps_module.cpp]
2026-08-16 initialize laser and sequence engine safely
2026-08-16 make ESP32-S3 the production Base target
2026-08-16 remove obsolete P4 wiring guide
2026-08-16 add WALL-E ESP32-S3 production CI
2026-08-16 make canonical Base sketch ESP32-S3 first
2026-08-16 make Base board map ESP32-S3 only
2026-08-16 use conflict-free ESP32-S3 Base GPIO map
2026-08-16 document ESP32-S3 WALL-E Base wiring
2026-08-17 fix WALL-E vision PlatformIO camera dependency
2026-08-17 make WALL-E deadman buttons fail safe
2026-08-17 enable WALL-E camera snapshot link safely
2026-08-17 fix WALL-E QMC5883L register setup
    [compass_sensor.cpp]
2026-08-17 add CYD Arduino ESP header compatibility shim
2026-08-17 preserve gravity during WALL-E IMU calibration
2026-08-17 pin CYD touchscreen driver to official upstream
